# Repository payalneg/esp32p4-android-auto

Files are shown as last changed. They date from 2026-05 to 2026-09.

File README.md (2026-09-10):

🇬🇧 **English** | 🇷🇺 [Русский](README.ru.md)

# VESC Dashboard for ESP32-P4 🛴⚡





[]()

Open-source **800×480 touch dashboard for VESC-powered e-vehicles** —
electric skateboards, e-bikes, scooters, DIY EVs. Live battery percent,
speed, motor / controller temps, voltage, current, odometer — straight off
the VESC CAN bus. Acts as a BLE bridge to VESC Tool so you can tune the
controller while the dashboard is running.

**Bonus**: the same device also speaks the native Android Auto Wireless
protocol — pair your phone over Bluetooth and Google Maps / Spotify /
Cycleway projects onto the same screen. No phone app required.

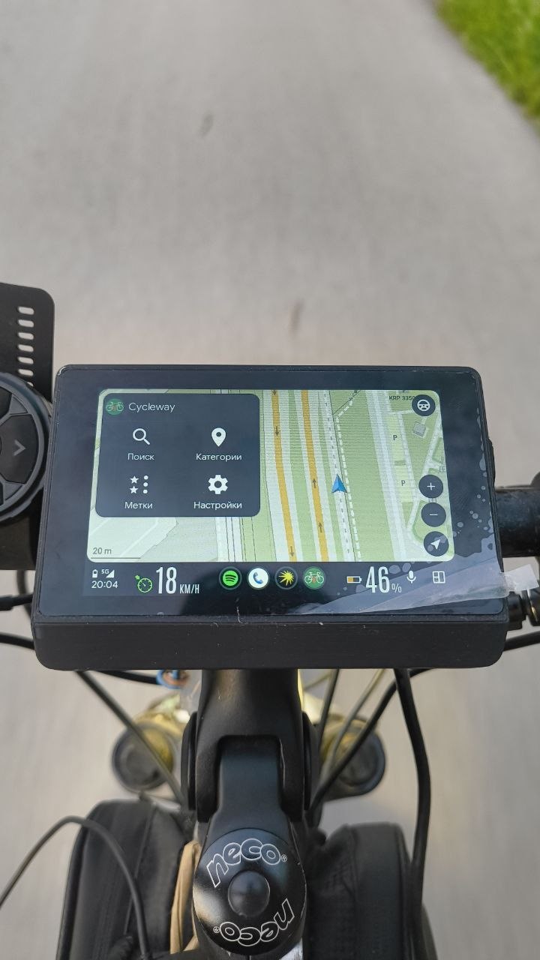
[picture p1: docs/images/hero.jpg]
VESC dashboard — battery, speed, voltage, odometer, motor / controller temps


> 🎬 Short ride demo: [`docs/demo.mp4`](docs/demo.mp4) · [`docs/demo-2.mp4`](docs/demo-2.mp4) · [`docs/demo-3.mp4`](docs/demo-3.mp4)

---

## ✨ Features

### 🛴 Primary — VESC dashboard
- **Live CAN telemetry**: battery %, speed, voltage, current draw, motor
  and FET temperatures, odometer, trip, range estimate, cruise indicator.
- **Trip tracking** — on-screen trip statistics window (distance, Wh,
  efficiency, charts) + a **Reset trip** button, backed by a raw circular
  trip log on a dedicated `triplog` flash partition that survives reboots.
- **On-device VESC Tool config menu** — read / write the controller's motor
  and app config straight from the dashboard screen, run FOC detection, keep
  config / trip backups — no laptop required. Parameter tables are
  code-generated from the VESC Tool XML.
- **BLE NUS bridge** — VESC Tool over Bluetooth Low Energy talks straight
  to the controller through this dashboard, no extra adapter needed.
- **Settings UI** on the device: CAN bitrate, controller ID, persisted
  units / preferences, in-PSRAM ring buffer log viewer.
- **HTTP OTA** with on-screen progress (`scripts/ota_push.sh`).

### 📺 Bonus — Wireless Android Auto
- Native **Android Auto Wireless** projection on the same 800×480 panel —
  no `Wireless Helper` APK, no developer-mode tricks. Pair phone over
  Classic BT once, AA launches itself on every power-on.
- H.264 video decode via `esp_h264` (SW decoder) + PPA-accelerated
  YUV420 → RGB565 shuffle. Native 800×480 @ ~10–15 fps on the panel.
- Touch input forwarded to the phone (GT911 capacitive controller).
- UI beeps / click feedback (System audio channel — required by Gearhead).
- Auto-reconnect to the last paired phone.

Android Auto Cycleway navigation projected on the same screen

### 📱 Companion app (optional)
`aa_bridge` — a small Flutter app ([`flutter-application/`](flutter-application/))
that talks to the head unit over BLE, independently of Android Auto:
- **Notification & media bridge** — phone notifications and now-playing
  metadata / album art mirrored onto the dashboard.
- **Wall clock** — pushes local time over BLE so the dashboard shows `HH:MM`
  with no on-device RTC / coin cell.
- **Firmware update over WiFi or BLE** — the P4 image is bundled in the APK and
  flashed to the head unit over its SoftAP (creds read over BLE automatically,
  or entered / scanned manually) or straight over the BLE link.
- **Device file manager** — browse the head unit's storage (`/vescfs` internal
  LittleFS + microSD) from the phone over BLE: list, download, upload, rename,
  delete. This is how you drop a boot-splash GIF onto the device.

### 🗂️ On-device file browser + boot splash
- **File browser** on the head unit itself (*Settings → Files*) — touch-driven,
  browses `/vescfs` (internal) and `/sdcard` (microSD): folders, sizes, image
  preview, rename / move / delete.
- **Boot splash** — drop an animated `splash.gif` into `/vescfs` and it plays
  full-screen during boot, then hands off to the dashboard. Absent → normal boot.

### 📦 Under the hood
- **Embedded co-firmwares**: ESP32-C6 (`esp-hosted` WiFi slave) and the
  D1 Mini Bluetooth agent are bundled inside the main binary and auto-flashed
  over SDIO / UART on version mismatch.
- **Dual-OTA** layout in 32 MB flash (both slots below the 16 MB boundary),
  plus a dedicated ~12 MB `triplog` partition above it for the raw trip log.

---

## 🔧 Hardware

| Part | Used for | Notes |
|---|---|---|
| **Waveshare ESP32-P4-WIFI6-Touch-LCD-4.3** | always | [Shop](https://www.waveshare.com/esp32-p4-wifi6-touch-lcd-4.3.htm). Main brain — ESP32-P4 + on-board ESP32-C6 WiFi, 800×480 ST7701 MIPI-DSI, GT911 touch. |
| **VESC controller with CAN out** | VESC dashboard | Any rev with CAN. This is the whole point. |
| **TJA1051 CAN transceiver** (prefer `T/3`) | VESC dashboard | 5V → 3.3V CAN level translation |
| **DC-DC step-down 12V → 5V** (≥1 A) | VESC dashboard | Power from VESC / vehicle battery |
| **ESP32-WROOM-32 module** (or any dev board with one) | Android Auto bonus | A bare WROOM-32 module soldered to the P4 board works fine — flip `BT_AGENT_OTA_ENABLED=y` in `idf.py menuconfig` and the P4 flashes it itself over the UART + RST/BOOT lines, no USB-to-serial needed. A D1 Mini ESP32 (or any USB-C ESP32 dev board with Classic BT) works too if you'd rather flash it directly. ESP32-P4 / C6 don't have BT Classic. ~$2–3. |
| Jumper wires, USB-C cables | always | |

If you don't care about Android Auto, you can drop the WROOM entirely —
the dashboard works standalone. With nothing connected on UART and
`BT_AGENT_OTA_ENABLED` left at its default `n`, the P4 silently no-ops
the BT path on every boot.

---

## 🔌 Wiring

<!-- TODO: close-up photo of the J3 header with VESC + D1 Mini wired in -->

**Pinout depends on the board.** The diagrams below are drawn for the
**Waveshare 4.3"** (the default board). For the **Guition JC4880P443C** take the
numbers from the JC4880 column; power, signal directions and the CAN RX divider
are the same on both boards.

| Signal | Waveshare 4.3" | JC4880P443C |
|---|---|---|
| CAN TX → transceiver TXD | GPIO 48 | GPIO 51 |
| CAN RX ← transceiver RXD | GPIO 47 | GPIO 52 |
| BT agent: P4 TX → WROOM RX | GPIO 22 | GPIO 33 |
| BT agent: P4 RX ← WROOM TX | GPIO 21 | GPIO 31 |
| BT agent RST → WROOM EN | GPIO 24 | GPIO 30 |
| BT agent IO0 → WROOM GPIO 0 | GPIO 25 | GPIO 29 |

### 1. Power chain

```text
 12 V battery        ┌────────────┐       ┌──────────────────┐        ┌────────────┐
 (VESC bus)  ───────▶│   DC-DC    │──────▶│  ESP32-P4 board  │───────▶│ WROOM 3V3  │
              +12 V  │ 12 V → 5 V │ +5 V  │  USB-C / 5V pin  │  3V3   │ (optional) │
                     │   ≥ 1 A    │       │  (on-board LDO)  │  (J3)  └────────────┘
                     └────────────┘       └──────────────────┘
```

> ⚠️ If you wire up a D1 Mini for the AA bonus, **power it from the P4's
> 3V3 rail, not from 5V**. The D1 Mini's on-board AMS1117 will burn the
> extra volt as heat for no reason — the P4 board already gives you clean
> 3.3 V on the J3 header.

### 2. VESC CAN bus (primary)

```text
  ESP32-P4                        TJA1051 (prefer T/3)        CAN bus
 ┌─────────────────┐            ┌───────────────┐
 │                 │            │               │
 │ GPIO 48 (TX) ───┼───────────▶│ TXD           │           ┌─────────────┐
 │                 │            │               │           │             │
 │ GPIO 47 (RX) ◀──┼─┬─[1.8kΩ]──┤ RXD      CANH ├─────┬─────┤ CANH        │
 │                 │ │          │               │  [120 Ω]  │    VESC     │
 │                 │[3.3kΩ]     │          CANL ├─────┴─────┤ CANL        │
 │                 │ │          │               │           │             │
 │            GND ─┼─┴──────────┤ GND           │           └─────────────┘
 │                 │            │               │
 │             5V ─┼───────────▶│ VCC           │
 └─────────────────┘            └───────────────┘
```

Pin direction is from the MCU's perspective (NXP convention): on the
TJA1051, **TXD is an input** (MCU drives it), **RXD is an output**
(transceiver drives the MCU).

- **Divider values on RXD**: 1.8 kΩ (series) + 3.3 kΩ (to GND) — or 10 kΩ + 18 kΩ.
  The TJA1051 runs off 5 V, so its RXD swings to 5 V — the divider brings it
  down to a P4-safe 3.3 V. TXD needs nothing: 3.3 V from the P4 drives it fine.
- **120 Ω terminator** across CANH ↔ CANL is **required** — a CAN bus without
  termination works flaky or not at all. Most TJA1051 breakout modules already
  have it soldered on board (look for a resistor marked `121` between the CANH
  and CANL terminals, or measure CANH↔CANL with the module unpowered: ~120 Ω =
  present, open = missing). If your module doesn't have it, **solder a 120 Ω
  resistor across CANH ↔ CANL** as shown in the diagram.
- **TJA1051 vs TJA1051T/3**: if you can choose, get the **T/3** variant — it
  has a dedicated `VIO` pin you can tie to 3.3 V and you can skip the divider
  entirely on RXD.
- Default CAN bitrate is **500 kbps**, controller ID **2** — both configurable
  in `idf.py menuconfig` under *VESC CAN* (`VESC_CAN_SPEED_KBPS`,
  `VESC_CAN_CONTROLLER_ID`).

#### Dual-motor (two-head) boards

Dual ESCs (Flipsky Dual, Spintend UBOX, MakerX dual, …) are **two VESC nodes on
one CAN bus**, each with its own controller ID. To use both heads:

1. In **Settings → Second head**, turn the toggle on and set **Second head ID**
   to the second controller's CAN ID (the primary is the usual *Target VESC ID*).
2. On **both** heads, in VESC Tool enable **App → General → Send status over CAN**
   with status messages **1–5** at **50 Hz** (the default rate when enabled), and
   give the two heads **distinct CAN IDs** (e.g. 0 and 1).

The 50 Hz status rate is required, not optional: the master VESC only folds a
peer into its combined totals while that peer's CAN status is **< 100 ms old**,
and the dashboard reads the second head's temperatures from those same status
frames. At a low status rate the combined Ah/Wh/power readout flickers.

What you get on a dual board:

- **Temperatures** show both heads as `h1/h2` (e.g. `34/37`); falls back to a
  single value if the second head's status isn't seen.
- **Battery / Ah / Wh / power** are the **combined** totals of both motors — the
  master VESC sums them itself (we just read its *setup* values), so no extra
  CAN polling is added.
- **Speed, distance and voltage** are taken from the primary head.
- **ESC NOT CONNECTED** shows if *either* head goes silent.
- The **VESC config menu** gains a **Head 1 / Head 2** selector so you can read
  and write each head's MCCONF/APPCONF independently.

### 3. D1 Mini ESP32 ↔ P4 (only for the AA bonus)

The P4 board exposes a `J3` header on the bottom edge with the free expansion
pins. The USB-C debug console (GPIO 37/38) stays usable while this is wired up.

```text
  ESP32-P4 (J3 header)             ESP32-WROOM-32 / D1 Mini
 ┌─────────────────────┐          ┌─────────────────────────┐
 │ GPIO 22 (UART1 TX) ─┼─────────▶│ GPIO 3 (RX0)            │
 │ GPIO 21 (UART1 RX) ◀┼──────────┤ GPIO 1 (TX0)            │
 │ GPIO 24 ────────────┼─────────▶│ EN     — chip reset     │
 │ GPIO 25 ────────────┼─────────▶│ GPIO 0 — boot select    │
 │ 3V3 (out) ──────────┼─────────▶│ 3V3    — power in       │
 │ GND ────────────────┼──────────┤ GND                     │
 └─────────────────────┘          └─────────────────────────┘
```

`EN` / `GPIO 0` are the standard ESP32 reset + boot-mode pins — same combo
the `esp_serial_flasher` uses on any ESP32 chip; on D1 Mini dev boards
they're already broken out to the `EN` and `D3` (= GPIO 0) headers
respectively.

The RST/BOOT lines let the main P4 firmware automatically re-flash the BT
agent over UART when their versions diverge — you only ever flash the D1 Mini
manually once.

---

## 🚀 Build & Flash

### Prerequisites

- **ESP-IDF v5.5 or newer** (tested with v5.5.3).
- Install both targets — `esp32p4` is mandatory, `esp32` only if you want
  the Android Auto bonus.

```bash
git clone --recursive https://github.com/espressif/esp-idf.git
cd esp-idf && ./install.sh esp32,esp32p4
. ./export.sh
```

### 1. Main firmware — ESP32-P4 (dashboard + AA)

```bash
cd esp32p4-android-auto
idf.py set-target esp32p4
idf.py -p /dev/cu.usbmodem* flash monitor
```

A plain `idf.py` build targets the **Waveshare 4.3"** board (the default).

> The ESP32-C6 WiFi co-firmware (`network_adapter.bin`) is bundled into the
> main binary via `EMBED_FILES` and pushed to the C6 over SDIO on boot when
> versions don't match — you don't flash the C6 separately.

#### Multiple boards

The firmware supports more than one board — and not all of them are ESP32-P4.
Pick the board with `scripts/build_board.sh <board> <idf.py args…>`, which uses
a per-board build directory and layers the matching
`sdkconfig.defaults.<board>` overlay:

| Board | Slug | Chip | Panel | Flash | Notes |
|---|---|---|---|---|---|
| Waveshare ESP32-P4-WIFI6-Touch-LCD-4.3 | `waveshare` | ESP32-P4 | 800×480 | 32 MB | default (also what plain `idf.py` builds) |
| Guition JC4880P443C_I_W | `jc4880` | ESP32-P4 | 800×480 | 16 MB | ST7701S, smaller partition table (`partitions_16mb.csv`) |
| Waveshare ESP32-S3-Touch-LCD-4 | `s3touch4` | ESP32-S3 | 480×480 | 16 MB | **VESC dashboard only, no Android Auto** — see [docs/board_s3touch4.md](docs/board_s3touch4.md) |

```bash
scripts/build_board.sh                              # build firmware for ALL boards
scripts/build_board.sh waveshare flash monitor
scripts/build_board.sh jc4880 -p /dev/cu.usbmodem* flash monitor
scripts/build_board.sh s3touch4 -p /dev/cu.usbmodem* flash monitor
```

Run with no board (or `all`) to build every board's image in one go.

What differs between the two P4 boards (everything else — WiFi/SDIO→C6, touch
I2C, SD, most of the I2S bus — is shared): MIPI-DSI panel timing + vendor init,
LCD backlight/reset pins, the BT-agent UART pins, the CAN RX/TX pins, flash
size and the partition table. The board is chosen by the Kconfig `BOARD_MODEL`
choice (`CONFIG_BOARD_WAVESHARE_43` / `CONFIG_BOARD_JC4880P443C` /
`CONFIG_BOARD_S3_TOUCH_LCD_4`); see the `#if CONFIG_BOARD_JC4880P443C`
branches in the BSP and `main/bt_link.h`.

The ESP32-S3 board is a bigger step sideways: its Wi-Fi and BLE are on the
chip itself (no ESP32-C6), its panel is a square 480×480 RGB one, and it has
no PPA blitter, no hardware JPEG and no external BT agent — so the whole
Android Auto side is compiled out (`CONFIG_AA_ENABLE`, ESP32-P4 only) and what
remains is the dashboard with CAN, BLE, pedal assist, trip history, the web UI
and OTA. It has its own 480×480 GUI Guider project (`Super_VESC_Display_480/`)
and its own BSP; `scripts/build_board.sh` switches `IDF_TARGET` for it.

The pins you actually wire (CAN transceiver and BT agent) are in the table under
**🔌 Wiring** above. JC4880's internal panel pins (LCD backlight `23`, reset `5`)
are set in the BSP — you don't solder those.
The 16 MB layout fits two 5 MB OTA slots + 1 MB storage + ~4.9 MB trip log —
the app image (~3.8 MB) has ~1.2 MB (24%) of headroom in each slot, so watch
the size as the firmware grows.

### 2. (Optional) BT agent firmware — D1 Mini ESP32

Only needed if you want the Android Auto bonus. Two ways to do it:

**A. Let the P4 flash it (best for a bare soldered WROOM).** Enable
`BT_AGENT_OTA_ENABLED=y` in `idf.py menuconfig` (under
*Project → BT Agent OTA*) and rebuild. On every boot the P4 checks the
agent's `BT-VER:` line over UART and reflashes it from the firmware blob
embedded in `components/bt_agent_fw/` if the version doesn't match. So a
bare soldered WROOM-32 comes up fully provisioned the first time you power
on. (Default is `n` — without it the BT path is a no-op even if a WROOM
is wired up.)

**B. Flash it yourself.** Plug a dev board with USB into your laptop:

```bash
cd tools/bt_agent
idf.py set-target esp32
idf.py -p /dev/cu.usbserial-* flash monitor
```

See [`tools/bt_agent/README.md`](tools/bt_agent/README.md) for the full agent
boot log walkthrough and what the SSP pairing dialogue looks like.

### 3. VESC LISP script — for cruise control + speed profiles

[`lisp/main.lisp`](lisp/main.lisp) runs on the **VESC controller** (not on
the P4). It adds cruise control via the PPM `RX` pin and three speed-profile
presets via `TX`, plus exposes the cruise state to the dashboard's LISP
poll channel — that's what drives the cruise indicator on screen.

Open *VESC Tool → VESC Packages → Lisp Scripting*, load `lisp/main.lisp`,
**Upload** → **Activate** → save to flash. See [`lisp/README.md`](lisp/README.md)
for details and how to customise the speed presets.

Without this script the dashboard still shows live telemetry — only the
cruise indicator and profile-switch beeps are lost.

### 4. OTA updates after the first flash

Once the head unit is on its SoftAP (default IP `192.168.4.1`), push new
firmware over HTTP from any laptop joined to the same AP:

```bash
scripts/ota_push.sh 192.168.4.1
```

You'll see a progress bar on the device screen, then it reboots into the new
slot.

---

## 📱 Using it

### Dashboard mode (default)

Power up. The dashboard comes up immediately on the screen showing whatever
the VESC is reporting over CAN — battery, speed, temps, etc. Tap into Settings
to change units, CAN bitrate, controller ID, or open the log viewer.

While the dashboard is running, **VESC Tool can connect over Bluetooth LE**
(NUS bridge) just like to any other VESC adapter.

### Switching between modes

**Three-finger tap** (any three fingers on the screen for ~100 ms) toggles
between the **VESC dashboard** and the **Android Auto projection**. The
gesture works in either direction, in both modes, and only fires once per
gesture — your fingers have to lift before it can fire again, so it won't
leak through to the phone as a stray touch.

### Android Auto bonus (after flashing the BT agent)

1. The screen also shows **"Waiting for phone"** in a corner with the SoftAP
   SSID / IP.
2. On the phone: *Settings → Bluetooth → Pair new device → **ESP32-P4 AA***.
3. Accept the SSP pairing prompt.
4. The phone joins the head unit's WiFi automatically and launches Android
   Auto. The screen flips to AA projection; the VESC dashboard runs on as
   an overlay (battery %, speed) on top of the AA video.

After the first pairing the head unit remembers the phone, and every
subsequent power-on auto-reconnects without prompts.

### Companion app (notifications, media, clock, WiFi flashing)

Optional Android app in [`flutter-application/`](flutter-application/). Build
and install:

```bash
cd flutter-application
flutter build apk --release
adb install -r build/app/outputs/flutter-apk/app-release.apk
```

- **Pair**: open the app → it scans for the head unit over BLE → tap to
  connect. Auto-reconnects after that.
- **Notifications / media**: grant the notification-access permission when
  prompted; phone notifications + now-playing info appear on the dashboard.
  The dashboard clock starts showing `HH:MM` once the app is connected.
- **Update firmware over WiFi**: *Home → Update head unit firmware*. The app
  reads the SoftAP credentials over BLE (or you scan / type them), joins that
  WiFi and uploads the firmware bundled in the APK. The head unit verifies and
  reboots onto the new version — keep it powered throughout. The bundled image
  is staged from `build/` by [`scripts/stage_firmware_asset.sh`](scripts/stage_firmware_asset.sh).

### Device files & boot splash GIF

Two ways to manage files on the head unit:

- **On device**: *Settings → Files* — a touch file browser over `/vescfs`
  (internal storage) and `/sdcard` (microSD if inserted). Browse, preview
  images, rename / move / delete.
- **From the phone**: *Home → Device files* (shown when connected to firmware
  that supports it) — list folders, download to the phone, upload from the
  phone, rename, delete, mkdir.
- **From a browser**: `http://android-auto.local/files` (or the SoftAP gateway
  IP) — the same browse / preview / upload / rename / move / delete over both
  drives.

### Web LISP editor

`http://android-auto.local/lisp` — a full LispBM editor for the script running
on the VESC, from any browser on the same network (the phone joins the head
unit's SoftAP anyway):

- syntax highlighting, line numbers, rainbow + matching parens, find/replace,
  block indent, auto-close;
- a linter for the mistakes that cost the most time here: paren balance,
  unterminated strings, `@const-start` / `@const-end` pairing, defuns left
  outside the const block, and threads started before the function they run
  is defined;
- the on-device script library (`/vescfs/lisp` and microSD) with open, save,
  rename / move, delete, mkdir and upload;
- **Read VESC** / **Upload** / **Upload + Run** / **Start** / **Stop** over CAN
  with a progress bar (the transfer runs asynchronously, so the rest of the
  server stays responsive);
- a live console of the script's `(print ...)` output, plus a REPL line for
  evaluating an expression without reflashing the script;
- LISP stats (CPU / heap / memory / stack and exported variables), polled only
  while that tab is open.

Turn it off with `CONFIG_LISP_HTTP_ENABLED=n` (costs ~15 KiB of flash).
`scripts/lisp_web_mock.py` serves the same page against a fake device, for
working on the editor without a board.

**Set a startup GIF**: upload an animated GIF to `/vescfs` via *Device files*
and name it **`splash.gif`** (upload it already named that, or rename it after
upload). On the next boot it plays full-screen, then the dashboard takes over.
Keep it small — `/vescfs` is ~4 MB on the Waveshare board, ~1 MB on jc4880.

---

## 🗺️ Roadmap / Status

| Area | Status | Notes |
|---|---|---|
| VESC RT data over CAN | ✅ | Battery %, speed, voltage, current, temps, odometer |
| Trip statistics window + persistent trip log | ✅ | Per-trip metrics / charts + Reset trip; raw circular log on the `triplog` partition |
| On-device VESC Tool config menu + FOC detection | ✅ | Read / write controller config from the screen; param tables generated from the VESC Tool XML |
| VESC LISP poll | ✅ | Cruise indicator + custom stats (requires [`lisp/main.lisp`](lisp/main.lisp) on the controller) |
| BLE NUS bridge (VESC Tool over BLE) | ✅ | Works concurrently with AA |
| Companion app — notifications / media / clock bridge | ✅ | Flutter `aa_bridge` over BLE |
| Companion app — firmware update over WiFi / BLE | ✅ | Bundled image POSTed to the SoftAP OTA endpoint, or streamed over the BLE link |
| On-device file browser (`/vescfs` + microSD) | ✅ | Touch UI in *Settings → Files*; image preview, rename / move / delete |
| Companion app — file manager over BLE | ✅ | Browse / download / upload / rename / delete the head unit's storage from the phone |
| Boot splash GIF | ✅ | Animated `/vescfs/splash.gif` shown during boot (upload via the app's file manager) |
| Settings UI + PSRAM log viewer | ✅ | Logs survive resets, viewable on device |
| HTTP OTA + on-screen progress | ✅ | `scripts/ota_push.sh` |
| (Bonus) AA Wireless video (H.264) | ✅ | Native 800×480 @ ~10–15 fps; SW decode + RGB shuffle is the bottleneck |
| (Bonus) Touch input forwarding | ✅ | GT911 → AA `TouchEvent` protobuf |
| (Bonus) System audio channel | ✅ | UI beeps; required by Gearhead to project at all |
| (Bonus) Auto-reconnect to last phone | ✅ | Bonded list in NVS on the BT agent |
| Media / Speech audio channels | 🟡 | Dropped on purpose — no audio sink |
| Pure BT Classic on P4 (no D1 Mini) | ❌ | Not possible — ESP32-P4 has no BT Classic radio |

---

## 🖨️ 3D-printable enclosure

STL / STEP files for the case live in [`3d-model/`](3d-model/). Print
settings, recommended materials and assembly notes will be added there as the
design firms up.

<!-- TODO: render or photo of the printed enclosure -->

---

## 📁 Repository layout

```
.
├── main/                       # ESP32-P4 firmware — VESC, UI, AA stack, OTA, BLE
├── components/
│   ├── esp32_p4_wifi6_touch_lcd_4_3/  # Waveshare BSP (LVGL, ST7701 DSI, GT911 touch)
│   ├── vesc_can/               # CAN driver for VESC (RT data + LISP poll)
│   ├── vesc_ui/                # Dashboard UI — thin wrapper; real UI source is globbed from Super_VESC_Display/{generated,custom}/
│   ├── vesc_config/            # On-device VESC Tool config menu (param tables from XML, FOC detection)
│   ├── trip_log/               # Raw circular trip log on the dedicated triplog partition
│   ├── dev_settings/           # Settings screen + persisted prefs
│   ├── log_capture/            # PSRAM ring-buffer logger
│   ├── bt_agent_fw/            # Embeddable bt_agent firmware blob (AA bonus)
│   ├── c6_ota_partition/       # Embedded ESP32-C6 firmware (network_adapter.bin)
│   └── qr_info/                # QR code with WiFi creds for the phone
├── Super_VESC_Display/         # NXP GUI Guider project — the dashboard UI source (generated/ + custom/), compiled into the firmware via vesc_ui
├── tools/
│   ├── bt_agent/               # D1 Mini ESP32 firmware (Classic BT + SPP)
│   ├── c6_slave_fw/            # Sources of the bundled C6 firmware (gitignored, see CLAUDE.md)
│   └── c6_ota_flasher/         # Standalone fallback C6 flasher
├── scripts/                    # capture.sh (Wireshark), ota_push.sh, extract_yuv.py, release.sh
├── lisp/                       # VESC LISP script (cruise + speed profiles) — runs on the VESC, not the P4
├── 3d-model/                   # STL / STEP files for the printed enclosure
├── release/                    # Versioned release artifacts (P4 .bin + companion .apk)
├── docs/images/                # Photos / screenshots used by this README
├── research/                   # Reference upstream sources (gitignored)
├── partitions.csv              # Dual-OTA layout (both slots below 16 MB) + triplog partition
├── CLAUDE.md                   # Original architecture notes / design history
└── README.md
```

---

## 🙏 Credits & references

- The **[VESC project](https://vesc-project.com/)** by *Benjamin Vedder* —
  the open-source motor controller this dashboard is built around.
- [**aasdk**](https://github.com/f1xpl/aasdk) and [**openauto**](https://github.com/f1xpl/openauto) by *f1xpl* — the AA Wireless protocol reference for the bonus mode.
- [**headunit-revived**](https://github.com/andreknieriem/headunit-revived) by *andreknieriem* — wireless-mode reference.
- [**esp-h264**](https://github.com/espressif/esp-h264) and [**esp-hosted**](https://github.com/espressif/esp-hosted) by *Espressif*.
- [**Waveshare ESP32-P4-WIFI6-Touch-LCD-4.3 wiki**](https://github.com/waveshareteam/ESP32-P4-WIFI6-Touch-LCD-4.3) — board BSP and example code.

---

## 📜 License

Released under the **GNU General Public License v3.0** — see [`LICENSE`](LICENSE).

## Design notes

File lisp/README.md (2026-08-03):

# VESC LISP script

`main.lisp` runs on the **VESC controller's** built-in LISP runtime (not on
the ESP32-P4). It does three things that the dashboard relies on:

1. **Cruise control** via the PPM `RX` pin button:
   - press once → lock current speed (switch into speed-control mode)
   - press throttle or brake → release cruise
   - the dashboard reads `cruise-active` over the LISP poll channel and
     lights the cruise indicator
2. **Speed profiles** — three presets (25 / 40 / 60 km/h, configurable in
   `apply-profile`), switchable two ways:
   - the PPM `TX` pin button cycles through them (`switch-profile`)
   - the on-screen panel picks one directly (`panel-set-profile`)
   Different beep tones confirm each profile change.
3. **Quick-action panel** — the swipe-out drawer on the P4 dashboard
   (left-edge swipe). This script is the *server* for it: the P4 asks
   "describe your controls" and we answer with a list the firmware renders
   (toggles / buttons / numbers / read-only values); interactions come back
   here. The starter set: **Throttle on/off**, a **Beep** button, a **Beep Vol**
   number (persisted) and the three **profile buttons** — a radio group, exactly
   one lit. A **Traction Control** toggle + sensitivity is included but commented
   out (single motor → native VESC TC is a no-op).

Without this script the dashboard still shows live telemetry (battery,
speed, voltage, temps over standard VESC CAN), but the cruise indicator,
profile switching and the quick-action panel won't work.

## Quick-action panel — describing the menu in LISP

The drawer is **data-driven**: this script tells the P4 *what controls to draw*,
the P4 renders them and sends back interactions. Nothing about the menu is
hard-coded in the firmware, so you change the menu by editing LISP only — no
firmware rebuild.

> **New here? Read "Add a control — the simple version" just below.** The
> byte-level sections after it are reference — you rarely need them.

### Add a control — the simple version

A control = one row in the drawer. You describe it in LISP, the P4 draws it.
Four kinds: **toggle** (on/off), **button** (press once), **number**
(−/value/+), **label** (read-only readout).

To add one, edit **3 spots** near the bottom of this file, all keyed by a
unique **id** number:

1. `panel-send-ui`    — bump the count, add one "describe" line.
2. `panel-send-state` — add its live value (skip for buttons).
3. `panel-action`     — say what happens when tapped (skip for labels).

Copy-paste templates — replace `ID`, `"Label"`, `myvar`, and the action:

```lisp
; TOGGLE  (on/off; myvar is 0 or 1)
;  ui:     (pu8 ID) (pu8 1) (pstr "Label") (pu8 myvar)
;  state:  (pu8 ID) (pi32 (* myvar 1000))
;  action: ((= cid ID) (setq myvar (if (> val 0.5) 1 0)))

; BUTTON  (momentary)
;  ui:     (pu8 ID) (pu8 2) (pstr "Label")
;  state:  — none —
;  action: ((= cid ID) (do-something))

; NUMBER  (−/value/+; this one is 0..100 step 5)
;  ui:     (pu8 ID) (pu8 3) (pstr "Label")
;          (pi32 0) (pi32 100000) (pi32 5000) (pi32 (* myvar 1000)) (pstr "")
;          ;        ^min×1000     ^max×1000   ^step×1000 ^value×1000 ^unit
;  state:  (pu8 ID) (pi32 (* myvar 1000))
;  action: ((= cid ID) (setq myvar (to-i32 val)))

; LABEL   (read-only; e.g. a live temperature)
;  ui:     (pu8 ID) (pu8 4) (pstr "Label") (pi32 (* (get-temp-mot) 1000)) (pstr "C")
;  state:  (pu8 ID) (pi32 (* (get-temp-mot) 1000))
;  action: — none —
```

Rules of thumb:
- **count** is the byte right after `0x81` (in `panel-send-ui`) / `0x82` (in
  `panel-send-state`). It must equal how many controls you actually list — add
  one, bump both.
- **id** is just a label; keep each unique, order doesn't matter.
- Numbers travel ×1000 (so `50` → `(pi32 (* 50 1000))`) — that's how decimals
  survive as whole numbers; the P4 divides back. Strings: `(pstr "...")`, empty
  unit = `(pstr "")`.

### Добавить контрол — по-простому

Контрол = одна строка в выезжающей панели. Ты описываешь её в LISP, а P4 рисует.
Четыре вида: **toggle** (вкл/выкл), **button** (нажал один раз), **number**
(−/значение/+), **label** (просто показать, без нажатия).

Чтобы добавить, правишь **3 места** внизу файла, всё завязано на уникальный
номер **id**:

1. `panel-send-ui`    — увеличь счётчик и добавь одну строку-«описание».
2. `panel-send-state` — добавь живое значение (для кнопки — не нужно).
3. `panel-action`     — что делать при нажатии (для label — не нужно).

Шаблоны — подставь `ID`, `"Название"`, `myvar` и действие:

```lisp
; TOGGLE  (вкл/выкл; myvar = 0 или 1)
;  ui:     (pu8 ID) (pu8 1) (pstr "Название") (pu8 myvar)
;  state:  (pu8 ID) (pi32 (* myvar 1000))
;  action: ((= cid ID) (setq myvar (if (> val 0.5) 1 0)))

; BUTTON  (разовое нажатие)
;  ui:     (pu8 ID) (pu8 2) (pstr "Название")
;  state:  — нет —
;  action: ((= cid ID) (что-то-сделать))

; NUMBER  (−/значение/+; тут 0..100 шаг 5)
;  ui:     (pu8 ID) (pu8 3) (pstr "Название")
;          (pi32 0) (pi32 100000) (pi32 5000) (pi32 (* myvar 1000)) (pstr "")
;          ;        ^мин×1000     ^макс×1000  ^шаг×1000  ^знач×1000  ^единица
;  state:  (pu8 ID) (pi32 (* myvar 1000))
;  action: ((= cid ID) (setq myvar (to-i32 val)))

; LABEL   (только показать; напр. температуру)
;  ui:     (pu8 ID) (pu8 4) (pstr "Название") (pi32 (* (get-temp-mot) 1000)) (pstr "C")
;  state:  (pu8 ID) (pi32 (* (get-temp-mot) 1000))
;  action: — нет —
```

Памятка:
- **count** — это байт сразу после `0x81` (в `panel-send-ui`) / `0x82` (в
  `panel-send-state`). Он должен равняться числу реально перечисленных контролов:
  добавил один — увеличь оба.
- **id** — просто метка; держи уникальным, порядок не важен.
- Числа едут ×1000 (`50` → `(pi32 (* 50 1000))`) — так дроби переживают пересылку
  целыми, P4 делит обратно. Строки: `(pstr "...")`, пустая единица = `(pstr "")`.

### How the conversation works

```
        user swipes from the left edge of the dashboard
                          │
  P4 ─ REQ_UI ──────────► us        "describe your controls"
  us ─ UI_DESC ─────────► P4        list of controls (this is the menu)
            … drawer rendered, then every ~200 ms while open:
  P4 ─ REQ_STATE ───────► us
  us ─ STATE ───────────► P4        live values (refresh toggles/numbers/labels)
        user taps a control
  P4 ─ ACTION ──────────► us        (control-id, new value)
  us ─ STATE ───────────► P4        echo the applied state back
```

> **Three copies of these rules exist and must stay in step.** This file is the
> human one. The in-app AI assistant is told the same protocol in
> `flutter-application/lib/agent/lisp_reference.dart` (byte layout) and
> `agent_prompt.dart` (the fail-silently rules), and
> `flutter-application/lib/agent/lisp_lint.dart` enforces it before letting the
> assistant flash. Change the wire format and you change all three, plus
> `components/vesc_can/`.

Transport is `COMM_CUSTOM_APP_DATA` (id 36): the firmware delivers inbound
frames to the `event-data-rx` event, and we answer with
`(send-data buf 2 reply-can-id)` — interface `2` is CAN, `reply-can-id` is the
P4's own controller id, which it puts in every request (needs VESC FW **6.05+**
for the explicit-interface form of `send-data`). The C side is
`components/vesc_can/vesc_lisp_panel.{c,h}`; everything below is its mirror.

### Conventions

- **Framing.** Every payload starts with the magic bytes `0x56 0x50` ('V' 'P'),
  then a 1-byte message type, then the body. The `COMM_CUSTOM_APP_DATA` byte
  itself is added/stripped by the firmware, so it never appears in `data` you
  receive or in the buffer you send.
- **Numbers are scaled integers.** Every float on the wire is
  `int32 = round(value * 1000)`, **big-endian**. So `0` → `0`, `100` → `100000`,
  `5` → `5000`, `tc-sens` → `(* tc-sens 1000.0)`. The P4 divides by 1000 again.
- **Strings are NUL-terminated.** A LISP string literal *is* a byte array that
  already ends in `0`, and `buflen` counts that terminator — so `(pstr "Beep")`
  emits `B e e p \0` and `(pstr "")` emits a single `\0` (used for "no suffix").

### Append helpers (already in `main.lisp`)

These write into the scratch buffer `pbuf` at the running index `pi`:

| helper | writes |
|---|---|
| `(pu8 v)` | one byte |
| `(pi32 v)` | `v` as big-endian int32 (you pre-multiply ×1000)|
| `(pstr s)` | the string `s` **including** its NUL terminator |

`pbuf` is `(bufcreate 128)` — zero-filled and over-sized on purpose: the P4 reads
exactly `count` controls and ignores trailing zeros, so you only need to grow
the `128` if a *single* reply gets bigger than that. The current `UI_DESC` is
102 B, so there is room for roughly one more short control before you must bump
it (the whole buffer goes on the wire every reply, so don't over-grow it).

### Message catalogue

**Inbound — what the P4 sends us** (`data`, magic already validated):

| msg | bytes |
|---|---|
| `REQ_UI` `0x01` | `[0]=V [1]=P [2]=0x01 [3]=reply-id` |
| `ACTION` `0x02` | `… [2]=0x02 [3]=reply-id [4]=ctrl-id [5..8]=i32 value*1000`  |
| `REQ_STATE` `0x03` | `… [2]=0x03 [3]=reply-id` |

**Outbound — what we send back** (`send-data pbuf 2 reply-id`):

```
UI_DESC (0x81):  0x56 0x50 0x81  <ver=1> <count>   then <count> controls
STATE   (0x82):  0x56 0x50 0x82  <count>           then <count> (id, value)
```

A control inside `UI_DESC` is `<id:u8> <type:u8> <label:str>` followed by a
type-specific tail:

| control | `type` | tail after `id type label` |
|---|:---:|---|
| toggle  | `1` | `<state:u8 0/1>` |
| button  | `2` | *(nothing)* — momentary |
| number  | `3` | `<min:i32> <max:i32> <step:i32> <value:i32> <suffix:str>` |
| label | `4` | `<value:i32> <suffix:str>` (read-only readout) |

An entry inside `STATE` is just `<id:u8> <value:i32>`. Send a value for every
control that can change (toggles, numbers, labels); buttons have no state, so
just leave them out of `STATE`.

**ACTION value semantics** (what arrives in `panel-action`): toggle → `0.0`/`1.0`,
button → `1.0` (a press), number → the new value in real units (e.g. `55.0`).

> Step-by-step with copy-paste templates is in **"Add a control — the simple
> version"** above. The current `main.lisp` panel is a live worked example:
> Throttle (toggle, id 1), Beep (button, id 4), Beep Vol (number, id 5, persisted)
> and the profile radio group — Slow / Medium / Fast (toggles, ids 10/11/12).
> Traction Control (ids 2/3) is there but commented out — a ready template to
> copy.
>
> **Radio group pattern** (the profiles): N toggles whose `state` is
> `(if (= sel K) 1 0)`, and each action sets `sel` to *its own* index while
> ignoring the incoming value. Tapping the lit row therefore sends `0` and does
> nothing — the `STATE` echo lights it straight back up.

## How to flash

Open **VESC Tool → VESC Packages → Lisp Scripting**, load
`lisp/main.lisp`, then **Upload** and **Activate**. Save to flash so it
survives reboot.

## Customising

- Speed presets — edit `apply-profile` (the three `conf-set 'max-speed`
  lines near the top of the file). Adding/removing one means: `num-profiles`,
  the `beep-freq` table, and the panel rows (ids 10..12 in `panel-send-ui` /
  `panel-send-state` / `panel-action`) — keep the labels in step with the
  speeds, the P4 only draws what this script says.
- Throttle/brake deadzones — `monitor-throttle-brake`.
- Quick-action panel controls — the `panel-*` functions at the bottom (see
  "Add a control — the simple version" above).
- Traction-control template — uncomment the TC controls + `monitor-traction`
  spawn; tune the `limit` formula. (Multi-motor only; no-op on a single motor.)

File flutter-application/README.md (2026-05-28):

# aa_bridge

A new Flutter project.

## Getting Started

This project is a starting point for a Flutter application.

A few resources to get you started if this is your first Flutter project:

- [Lab: Write your first Flutter app](https://docs.flutter.dev/get-started/codelab)
- [Cookbook: Useful Flutter samples](https://docs.flutter.dev/cookbook)

For help getting started with Flutter development, view the
[online documentation](https://docs.flutter.dev/), which offers tutorials,
samples, guidance on mobile development, and a full API reference.

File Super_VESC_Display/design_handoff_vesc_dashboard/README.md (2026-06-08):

# Handoff: VESC E-Bike Dashboard (Cyberpunk Amber)

## Overview
A full-screen instrument cluster for an electric bike running a **VESC** motor controller.
Target hardware display: **800 × 480 px** (landscape, fixed resolution).
The design shows live ride telemetry — speed, battery, power, temperatures — in a
"cyberpunk" amber-on-black aesthetic with a 7-segment LCD numeric typeface and warm glow.

The chosen direction is **Variant A — "Classic Reskin"**: it keeps the exact information
layout of the original VESC stock display (battery left, big speed center, power right,
secondary readouts along the bottom) and reskins it.

## About the Design Files
The files in this bundle are **design references created in HTML/React (via Babel in the
browser)** — a prototype showing the intended look and behavior. They are **not** meant to
be shipped as-is to the device.

The task is to **recreate this design in the target environment** for the VESC display —
e.g. an embedded UI framework (LVGL/C, Qt/QML), a React/web kiosk, or whatever renders on
the actual screen — using that environment's patterns. If no environment exists yet, pick
the most appropriate one for an 800×480 embedded display. Treat the HTML as the visual
spec, not the implementation.

## Fidelity
**High-fidelity (hifi).** Final colors, typography, spacing, layout and glow treatment are
all intended as-shown. Recreate pixel-accurately at 800×480. The numbers shown are sample
telemetry values (see Design Tokens → Sample data) — wire them to real VESC data.

## Canvas / Coordinate system
- Fixed art-board: **800 × 480 px**, origin top-left. All measurements below are in this space.
- The screen is divided into 3 horizontal bands:
  - **Top status bar** — height **50px**
  - **Main row** — height **340px** (battery | speed | power)
  - **Bottom readout row** — height **90px**
  - (50 + 340 + 90 = 480)

## Screens / Views

### Screen: Ride Dashboard (single screen)
**Purpose:** at-a-glance riding telemetry.

**Layout (top → bottom):**

**1. Top status bar** (`height 50px`, padding `0 20px`, bottom border `1px solid rgba(255,122,26,0.14)`)
A single flex row, `justify-content: space-between`, font-size 17px:
- `VESC MODE` (nav label, amber-bright, glow-s)
- trip timer `0:48:12` (7-seg, 18px, opacity .8)
- `STATISTICS` (nav label)
- clock `14:32` (7-seg, 18px, opacity .8)
- `SETTINGS` (nav label)
- Bluetooth group: a 8px blue dot (`#2aa9ff`, glow) + `BT` label in blue
  Nav labels: font Chakra Petch 700, letter-spacing .12em, uppercase, `white-space: nowrap`.

**2. Main row** (`height 340px`, flex row):

  **a) BATTERY column** — fixed width **210px**, padding `16px 18px 10px`, right border `1px solid grid-line`, flex column:
  - `BATTERY` label (Chakra Petch 600, 22px, uppercase, letter-spacing .18em, color `--label`)
  - Value row (margin-top 14px, align-items baseline, gap 8px): big `73` (7-seg, **46px, "hot" style**) + `%` unit (22px)
  - Sub row (margin-top 6px, gap 6px): `6.4` (7-seg, 24px, **no ghost**) + `Ah` unit (16px)
  - **Vertical segmented bar** — fills remaining height (`flex:1`, margin `12px 0 8px`), 16 cells, fill from bottom, `73%` lit
  - Footer row (space-between, baseline): `RANGE` label (16px) + `38` (7-seg 24px, no ghost) + `KM` unit (15px)

  **b) SPEED column** — `flex: 1` (center), flex column centered:
  - `SPEED · KM/H` label (Chakra Petch 600, 17px, letter-spacing .32em, nowrap, **margin-bottom 20px**)
  - `42` — the hero number (7-seg, **166px, "hot" style**, line-height .9). Value is zero-padded to 2 digits.
  - `SPORT` — ride mode label (Chakra Petch 600, 15px, letter-spacing .3em, color `--amber`, margin-top 18px)
  - *(Note: an earlier version had a curved "smile" arc gauge under the speed — it was intentionally removed. Do not add it.)*

  **c) POWER column** — fixed width **210px**, padding `16px 18px 10px`, left border `1px solid grid-line`, flex column, **right-aligned** (`align-items: flex-end`):
  - `POWER` label (22px)
  - Value row (baseline, gap 8px): `2.8` (7-seg, **46px, hot**) + `kW` unit (22px)
  - Sub row (gap 6px): `24.5` (7-seg, 24px, no ghost) + `A` unit (16px)
  - **Vertical segmented bar** — fills remaining height, 16 cells, lit to `power/maxKw` = `2.8/4.5 ≈ 62%`, **warn (red) above 80%**
  - Footer row (space-between, full width, baseline): `MAX` label (16px) + `4.5` (7-seg 24px, no ghost) + `KW` unit (15px)

**3. Bottom readout row** (`height 90px`, top border `1px solid grid-line`, flex row of 5 equal cells):
Each cell: flex column, centered, gap 7px, left border `1px solid grid-line` (except first). Contains a small label (Chakra Petch 600, 14px) above a value (7-seg, 26px, no ghost) + unit (14px). The five cells:
1. `VOLTAGE` — `58.4` `V`
2. `TRIP` — `12.6` `KM`
3. `ODO` — `6436` `KM`
4. `M·TEMP` — `47` `°C`  (motor temp; turns **red/warn** if > 70)
5. `C·TEMP` — `39` `°C`  (controller temp; turns **red/warn** if > 70)

## Components (reusable primitives)

### `Seg` — 7-segment numeric readout
The signature element. A number rendered in the **DSEG7 Classic** font with a warm glow.
Behind the lit value sits an optional dim "ghost" layer showing all segments as `8`s
(simulating unlit LCD segments) at `--amber-dim` with no glow.
- Props/states:
  - **default**: value color `--amber-bright`, text-shadow `--glow-m`
  - **hot** (`.hot`): value color `--amber-hot` (`#ffe6c2`), text-shadow `--glow-l` — used for the hero numbers (speed, battery %, power kW, current/maxKw big values)
  - **warn** (`.warn`): value color `--red` (`#ff3b2f`), red glow — used for over-temp
  - **ghost** on/off: ghost backdrop is ON for large hero numbers only; OFF for all small/secondary numbers (Ah, range, current, max, and the whole bottom row), because the leading-digit ghost looked like an artifact on short values.
- Ghost text = value with every digit replaced by `8`.

### `SegBar` — vertical segmented bar gauge
- Column of N equal cells (default 16), `flex-direction: column-reverse` so it fills from the bottom, `gap 4px`.
- Cell off: background `--amber-dim`, radius 2px, subtle inset border.
- Cell on: background `linear-gradient(90deg, --amber-deep, --amber)`, glow-s + inner highlight.
- Cell warn+on: red gradient (`#9c1500 → --red`) + red glow. `warnAbove` prop = % threshold above which lit cells go red.
- Lit count = `round(count * pct / 100)`.

### Labels
- `.lbl` — section/field labels: Chakra Petch 600, uppercase, letter-spacing .18em, color `--label`.
- `.unit` — unit suffixes: Chakra Petch 600, letter-spacing .08em, color `--label`.
- `.navitem` — top-bar items: Chakra Petch 700, letter-spacing .12em, nowrap; `.active` adds amber-bright + glow-s.

## Screen treatment (the "fx" overlay)
The whole panel (`.scr`) has:
- Background: near-black `--bg` (#0a0806) with two warm radial gradients (top-center orange wash + bottom warm glow).
- A non-interactive overlay (`.fx::after`, z-index 50) combining:
  - **Scanlines**: `repeating-linear-gradient(to bottom, transparent 0 2px, rgba(0,0,0,0.16) 2px 3px)`
  - **Vignette**: `radial-gradient(130% 100% at 50% 50%, transparent 55%, rgba(0,0,0,0.55) 100%)`
- `-webkit-font-smoothing: antialiased`, `user-select: none`.

## Interactions & Behavior
This is currently a **static mockup** with sample values. For the real device, drive these from VESC telemetry:
- **speed** → hero number (km/h, zero-padded to 2 digits)
- **battery %** + **Ah used** + **range (km)** → battery column + left bar (bar = battery %)
- **power kW** + **current A** + **max kW** → power column + right bar (bar = power/maxKw %, red above 80%)
- **voltage, trip, odo, motor temp, controller temp** → bottom row
- **temps** flip to red/warn when > 70 °C (threshold is illustrative — set to the real safe limit).
- **clock** + **trip timer** → top bar.
- Top-bar items (`VESC MODE / STATISTICS / SETTINGS`) are placeholders for navigation to other screens (not yet designed).

Suggested polish for implementation (not in the mock): animate numeric changes, ease bar fills, smooth glow. Keep updates ≤ a few Hz to avoid flicker on the embedded panel.

## State Management
Minimal — a single telemetry object updated from the controller. Shape (see `DATA` in `variant-classic.jsx`):
```
{ speed, mode, batPct, batAh, range, powerKw, current, maxKw,
  voltage, trip, odo, mTemp, cTemp, clock, tripTime }
```

## Design Tokens

### Colors
| Token | Value | Use |
|---|---|---|
| `--bg` | `#0a0806` | screen background |
| `--bg-panel` | `#100b07` | panel background |
| `--amber` | `#ff7a1a` | primary amber (bars, accents) |
| `--amber-bright` | `#ffb35c` | default lit digit |
| `--amber-hot` | `#ffe6c2` | hero digit (hottest) |
| `--amber-deep` | `#c8470a` | gradient base for lit bar cells |
| `--amber-dim` | `rgba(255,122,26,0.09)` | unlit segment ghost / off bar cell |
| `--amber-dim2` | `rgba(255,122,26,0.16)` | faint fills |
| `--grid-line` | `rgba(255,122,26,0.14)` | dividers / borders |
| `--red` | `#ff3b2f` | warn / over-temp |
| `--label` | `rgba(255,176,110,0.55)` | labels & units |
| `--label-dim` | `rgba(255,176,110,0.35)` | idle labels |
| Bluetooth blue | `#2aa9ff` | BT dot + label |

### Glows (text-shadow / drop-shadow)
| Token | Value |
|---|---|
| `--glow-s` | `0 0 6px rgba(255,122,26,.55), 0 0 16px rgba(255,90,0,.35)` |
| `--glow-m` | `0 0 10px rgba(255,138,30,.6), 0 0 30px rgba(255,90,0,.4)` |
| `--glow-l` | `0 0 16px rgba(255,150,40,.7), 0 0 50px rgba(255,90,0,.45), 0 0 90px rgba(255,70,0,.25)` |
| warn glow | `0 0 10px rgba(255,59,47,.7), 0 0 28px rgba(255,40,0,.4)` |

### Typography
- **Numeric / readouts:** `DSEG7 Classic` (7-segment LCD font). Source used in mock: `@fontsource/dseg7-classic` (weights 400 & 700). On device, embed an equivalent 7-segment font. Fallback `monospace`.
- **Labels / UI:** `Chakra Petch` (Google Fonts), weights 400/500/600/700.
- Sizes (px): hero speed **166**; section big values **46**; secondary values **24–26**; section labels **22**; bottom labels **14**; unit suffixes **14–22**; top-bar **17**.
- Letter-spacing: labels .18em, SPEED label .32em, mode .3em, nav .12em.

### Spacing / layout
- Bands: 50 / 340 / 90 px. Side columns 210px each, center flexes.
- Column padding `16px 18px 10px`. Bar cell gap 4px, cell radius 2px.
- Borders/dividers all `1px solid --grid-line`.

### Sample data (placeholder telemetry)
`speed 42 (SPORT) · battery 73% · 6.4 Ah · range 38 km · power 2.8 kW · current 24.5 A · max 4.5 kW · voltage 58.4 V · trip 12.6 km · odo 6436 km · motor 47 °C · controller 39 °C · timer 0:48:12 · clock 14:32`

## Assets
- `reference_original_display.png` — photo of the stock VESC display this layout mirrors.
- `reference_cyberpunk_style.png` — the cyberpunk amber style reference the look is based on.
- Fonts are loaded from CDN in the mock (Google Fonts: Chakra Petch; jsDelivr: DSEG7). For the device, **bundle** both font files locally — do not rely on the CDN.

## Files in this bundle
- `VESC Dashboard (Variant A).html` — standalone, self-scaling reference page. Open in a browser to see the target. (It letterboxes the fixed 800×480 panel to fit the window.)
- `variant-classic.jsx` — the React/Babel source for Variant A and its primitives (`Seg`, `SegBar`, `BottomRow`, `Topbar`). This is the authoritative structural reference.
- `styles.css` — all design tokens, the 7-seg/ghost treatment, bar styles, and the scanline/vignette overlay.

> Note: `variant-classic.jsx` also exports two unused primitives (`SegRow`, `SmileArc`) and a `DASH` bundle that other (non-included) variants consumed. `SmileArc` is the removed speed arc — ignore both unless you want them.

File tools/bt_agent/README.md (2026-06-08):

# Bluetooth Classic Agent (D1 Mini ESP32-WROOM-32)

Standalone ESP-IDF project that runs on a **D1 Mini ESP32** (or any
ESP32-WROOM-32-based board) and acts as the Classic Bluetooth front-end for
the ESP32-P4 Android Auto head unit. It exists to defeat the modern
"Cakewalk" wireless-AA flow that Google rolled out in late 2023, which
silently blocks projection to head units that haven't gone through a real BT
pairing handshake.

## Wiring to the Waveshare ESP32-P4 board

J3 header on the bottom edge:

```
D1 Mini side             ESP32-P4 (J3)
─────────────────────────────────────────
GPIO 1 (TX0)    ────►    GPIO 21  (RX)
GPIO 3 (RX0)    ◄────    GPIO 22  (TX)
GND             ────     GND
5V (or VBUS)    ◄────    5V
```

The agent talks over **UART0** (the standard USB-Serial pins, GPIO 1/3).
The UART2 pads (GPIO 16/17) didn't reliably drive a 3.3 V signal on this
D1 Mini clone — on some clones those pins route to the CH9102 auto-program
circuit — so UART0 is the only path that moves data in both directions.
Trade-off: the on-board CH9102 USB-to-UART bridge shares these lines, so
the USB console and the P4 link both ride GPIO 1/3.

GPIO 21/22 on P4 are free expansion pins, so the USB-C debug console on P4
(GPIO 37/38) stays usable while the agent is wired up.

## Build & flash

The agent's UART link to P4 rides the same GPIO 1 (TX0) / GPIO 3 (RX0)
pins as the on-board CH9102 USB-Serial bridge, so the wires to P4 and the
USB-C cable fight over those lines. Flash in this order:

1. unplug the wires from P4 (GPIO 1 / GPIO 3 / GND / 5V)
2. plug in USB-C, run `idf.py flash` below
3. unplug USB-C, reconnect the wires to P4

Plug the D1 Mini into your laptop via its **USB-C** port. Find the serial
port (usually `/dev/cu.usbserial-XXXX` on macOS), then from this directory:

```
. ~/.espressif/v5.5.3/esp-idf/export.sh   # or wherever IDF lives
idf.py set-target esp32                   # only first time
idf.py -p /dev/cu.usbserial-XXXX flash monitor
```

First build pulls some BT components and is slow (couple of minutes).
Subsequent builds are quick.

## What you should see in the monitor

Boot output:

```
I (NNN) bt_agent: BT classic + SPP up. Discoverable as 'ESP32-P4 AA' (Car Audio)
```

Then on the phone, go to `Settings → Bluetooth → Pair new device` and you
should see **ESP32-P4 AA**. Tap it, accept the pairing prompt. The monitor
should print:

```
I (NNN) bt_agent: SSP confirm req num=... — accepting
I (NNN) bt_agent: auth ok with '<phone-name>'
I (NNN) bt_agent: SPP client connected: handle=...
I (NNN) bt_agent: TX msg=1 payload=N bytes        (WifiStartRequest)
I (NNN) bt_agent: RX msg=2 payload=0 bytes        (WifiInfoRequest)
I (NNN) bt_agent: TX msg=3 payload=N bytes        (WifiInfoResponse)
```

After the WifiInfoResponse, Android Auto on the phone should auto-launch
and try to connect to the P4 head unit at the IP/port we advertised.

## Configuration

`main/main.c` has hard-coded credentials at the top:

- `HU_WIFI_SSID` / `HU_WIFI_PASS` — the LAN credentials to hand to the
  phone. Must match what `main/bench_wifi.h` on the P4 contains.
- `HU_LAN_IP` — IP the P4 currently has (DHCP-assigned). Hard-coded for
  now; future revision will receive it from P4 via UART.
- `HU_LAN_PORT` — TCP port the AAP receiver listens on (5288).

## UART signals to P4 (for future P4-side coordination)

Single line per event, ending in `\n`:

| Line | Meaning |
|---|---|
| `BT:BOOT` | Agent just powered on |
| `BT:READY` | SPP server up, waiting for phone |
| `BT:PAIRED` | Phone completed Classic BT auth |
| `BT:CONNECTED` | Phone opened the SPP/RFCOMM channel |
| `BT:WIFI_INFO_SENT` | Sent WifiInfoResponse with creds |
| `BT:WIFI_CONNECT_STATUS` | Phone reported WifiConnectStatus |
| `BT:DISCONNECTED` | SPP channel closed |

P4 doesn't need to read these for the BT pairing experiment to work, but
they're useful for the eventual Mode A coordination layer.

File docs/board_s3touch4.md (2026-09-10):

# Waveshare ESP32-S3-Touch-LCD-4 (`s3touch4`)

The dashboard-only board: same firmware tree, same VESC dashboard, no Android
Auto. Written down here because the two hardware revisions differ in a way that
looks like a dead display if you guess wrong.

## Module and panel

| | |
|---|---|
| MCU | ESP32-S3-WROOM-1-N16R8 — dual Xtensa @240 MHz, 512 KB SRAM, 16 MB flash, 8 MB **octal** PSRAM |
| Panel | 4", 480×480, ST7701, RGB565 over the 16-bit RGB bus; controller registers over a 3-wire SPI link during init only |
| Touch | GT911, I²C, address 0x5D (0x14 on some units) |
| Radio | on-chip Wi-Fi + BLE 5 — no ESP32-C6, no ESP-Hosted |
| Console | USB-C is the chip's native USB (USB-Serial-JTAG), not a bridge chip |

## Pins

Shared I²C bus: **SDA GPIO15, SCL GPIO7** — touch, the PCF85063A RTC (0x51) and
the board helper all hang off it.

```
RGB   DE 40   VSYNC 39   HSYNC 38   PCLK 41
      B0-B4   5, 45, 48, 47, 21
      G0-G5   14, 13, 12, 11, 10, 9
      R0-R4   46, 3, 8, 18, 17
LCD   3-wire SPI: CS 42, SCL 2, SDA 1     (init only)
SD    1-bit SDMMC: CLK 2, CMD 1, D0 4     (shares CLK/CMD with the LCD link)
CAN   TX 6, RX 0        (TJA1051 on the external header)
RS485 TX 44, RX 43      (not used by this firmware)
```

The SD card and the LCD's control link share GPIO 1 and 2. The ST7701 only
needs that link while it is being initialised, so the card must not be mounted
before `bsp_display_new()` has run — which is the order the firmware boots in.

## Hardware revision — check before flashing

| | V4.0 | V3.0 |
|---|---|---|
| Helper on I²C | CH32V003 at **0x24** | TCA9554 at **0x20** |
| Backlight | PWM, 0–255 (inverted duty) | enable pin only, on/off |
| Also driven | LCD reset, touch reset, system power, buzzer, battery ADC | LCD reset, touch reset, backlight enable |
| Kconfig | `CONFIG_BSP_S3T4_HW_V4` (default) | `CONFIG_BSP_S3T4_HW_V3` |

Tell them apart from the silkscreen, or by which address answers on the bus.
The BSP logs `no IO expander at 0x…` and names the wrong-revision case when it
cannot find the one it was built for. With the wrong revision selected the
panel typically comes up after a warm reset and stays black after a power
cycle, because nothing pulses its reset line.

On V3.0 the brightness slider in Settings degrades to a switch: any value above
zero is full brightness.

Vendor material (schematic, examples, the CH32V003 and RTC components) is at
<https://github.com/waveshareteam/ESP32-S3-Touch-LCD-4> — see CLAUDE.md for the
clone line.

## Memory budget

Internal RAM is the constraint, PSRAM is merely tight:

| | |
|---|---|
| Two 480×480 RGB565 framebuffers | 920 KB PSRAM |
| `.text` + `.rodata` copy (XIP from PSRAM) | ~2.5 MB PSRAM |
| Boot-log ring (`CONFIG_LOG_CAPTURE_SIZE_KB`) | 256 KB PSRAM |
| Notification icon cache, LISP buffers, album art | ~0.6 MB PSRAM |
| LVGL heap (all of it — `LV_MEM_CUSTOM` allocates from PSRAM) | rest |

`CONFIG_SPIRAM_FETCH_INSTRUCTIONS` + `CONFIG_SPIRAM_RODATA` are what keep the
RGB panel from tearing when something writes flash: the LCD's DMA reads its
framebuffer through the cache, and without XIP-from-PSRAM every NVS commit
would disable that cache. It costs the 2.5 MB above, which is why Wi-Fi OTA
falls back to streaming instead of staging the whole image, and why BLE OTA can
run out of PSRAM and ask you to use Wi-Fi instead.

## Bring-up checklist

1. Identify the revision (above) and set it in `menuconfig` if it is V3.0:
   `scripts/build_board.sh s3touch4 menuconfig` → Board Support Package.
2. `scripts/build_board.sh s3touch4 -p /dev/cu.usbmodem* flash monitor`.
3. In the boot log check: `spi_flash` reports 16 MB, `display_init` starts
   printing `render: N fps | avg …ms`, `wifi_manager` brings up the SoftAP,
   `comm_can` starts on TX 6 / RX 0.
4. Watch the panel while something writes flash (open Settings and change a
   value, or run an OTA): no tearing or sideways drift. If it does drift, the
   next lever is `CONFIG_BSP_LCD_RGB_BOUNCE_BUFFER_HEIGHT`, then re-arming
   `flash_shade` (see `main/display_init.c`).

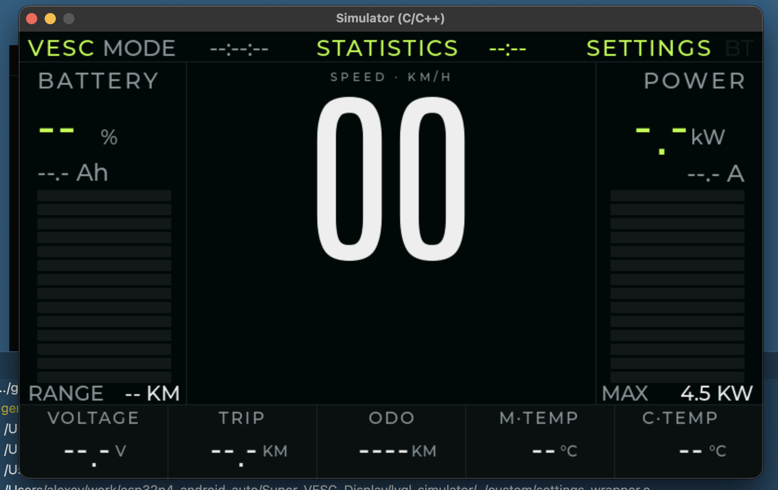
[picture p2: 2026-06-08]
Super_VESC_Display/design_handoff_vesc_dashboard/reference_cyberpunk_style.png

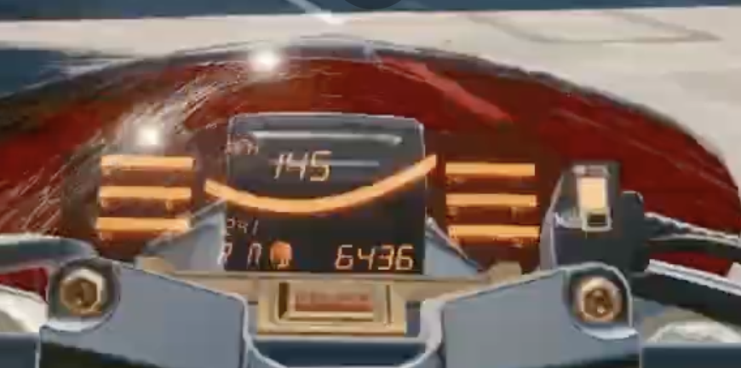
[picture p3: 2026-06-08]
Super_VESC_Display/design_handoff_vesc_dashboard/reference_original_display.png

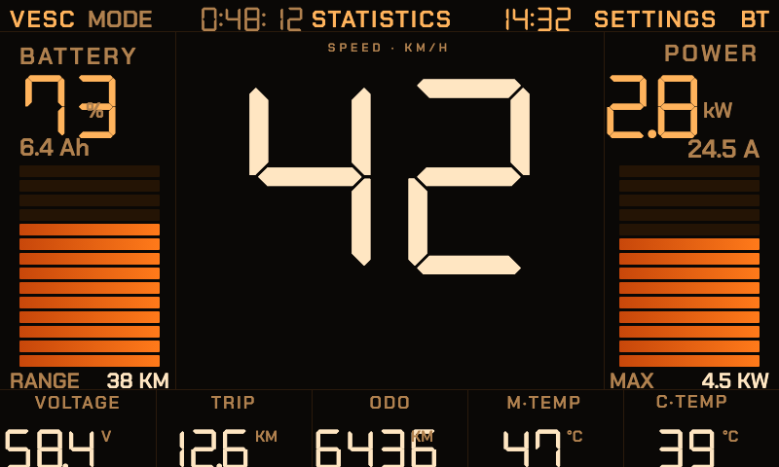
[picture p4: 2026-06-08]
Super_VESC_Display/design_handoff_vesc_dashboard/amber_dashboard_preview.png

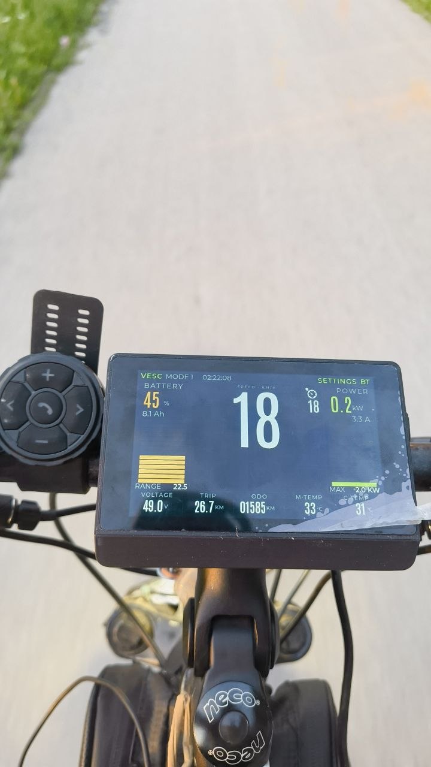
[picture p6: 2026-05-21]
docs/images/vesc-hud.jpg

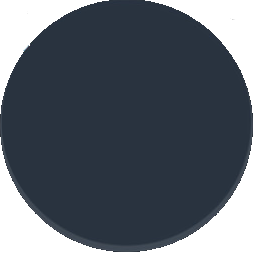
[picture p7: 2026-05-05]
Super_VESC_Display/import/image/speed_background.png

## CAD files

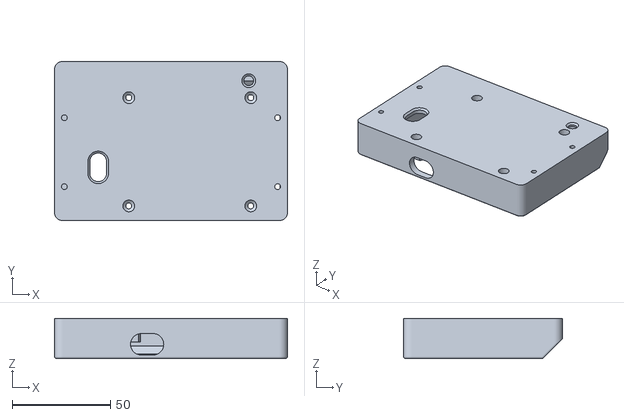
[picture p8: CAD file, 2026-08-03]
3d-model/esp32-p4-wifi6-guiton-800x480/main.stl
118.4 x 80.8 x 20.5

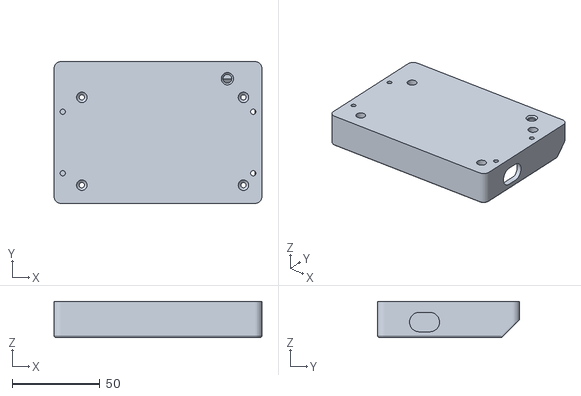
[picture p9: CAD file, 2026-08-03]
3d-model/esp32-p4-wifi6-waveshare/main.stl
118.4 x 80.8 x 20.5

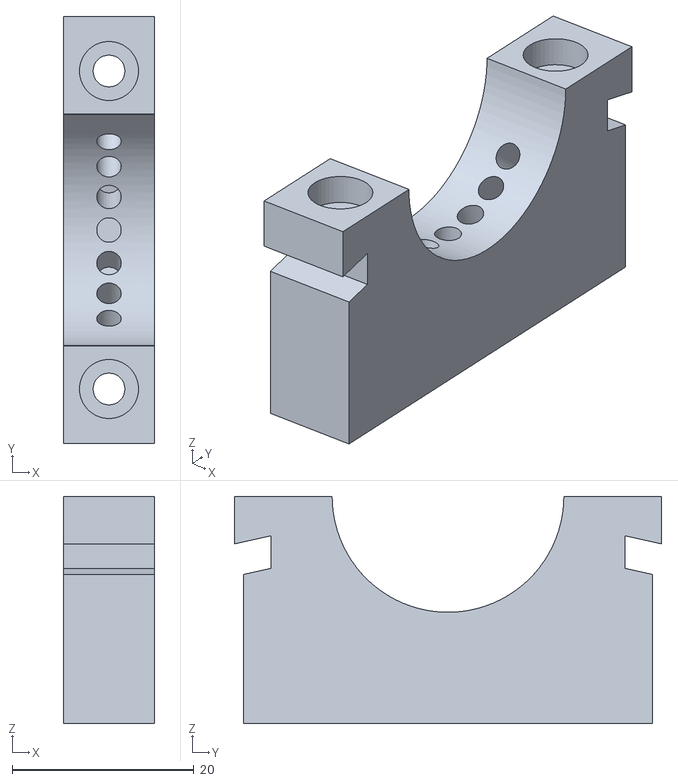
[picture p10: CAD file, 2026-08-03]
3d-model/esp32-p4-wifi6-guiton-800x480/u-holder.stl
10.0 x 47.0 x 25.0

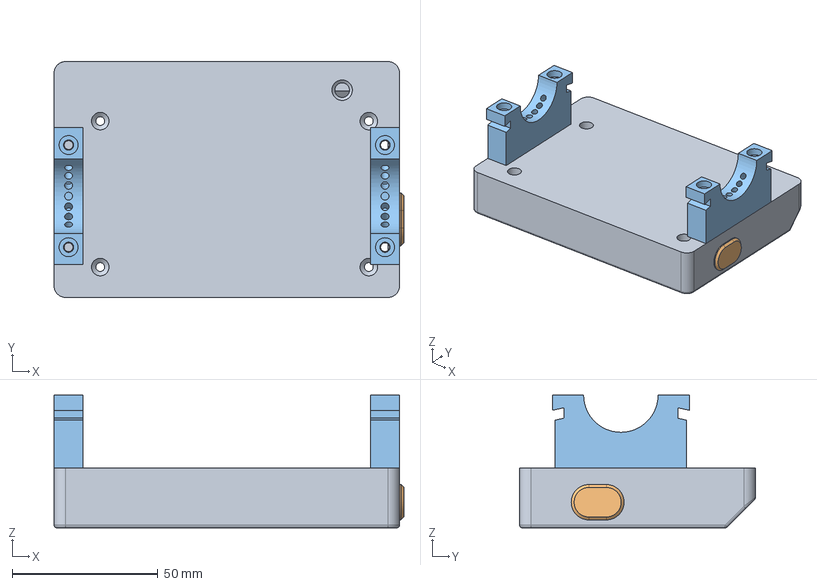
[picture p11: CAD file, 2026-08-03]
3d-model/esp32-p4-wifi6-waveshare/esp32-p4-wifi6-waveshare-800x480.step
119.9 x 80.8 x 45.5 mm
Main
cover-TPU
u-holder x 2
insert

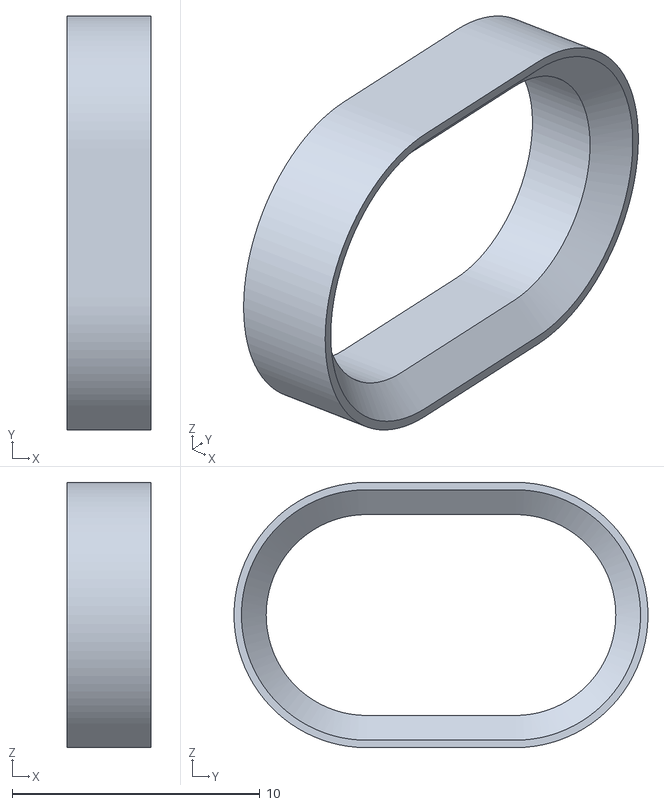
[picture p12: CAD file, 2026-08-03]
3d-model/esp32-p4-wifi6-waveshare/insert.stl
3.40 x 16.7 x 10.7

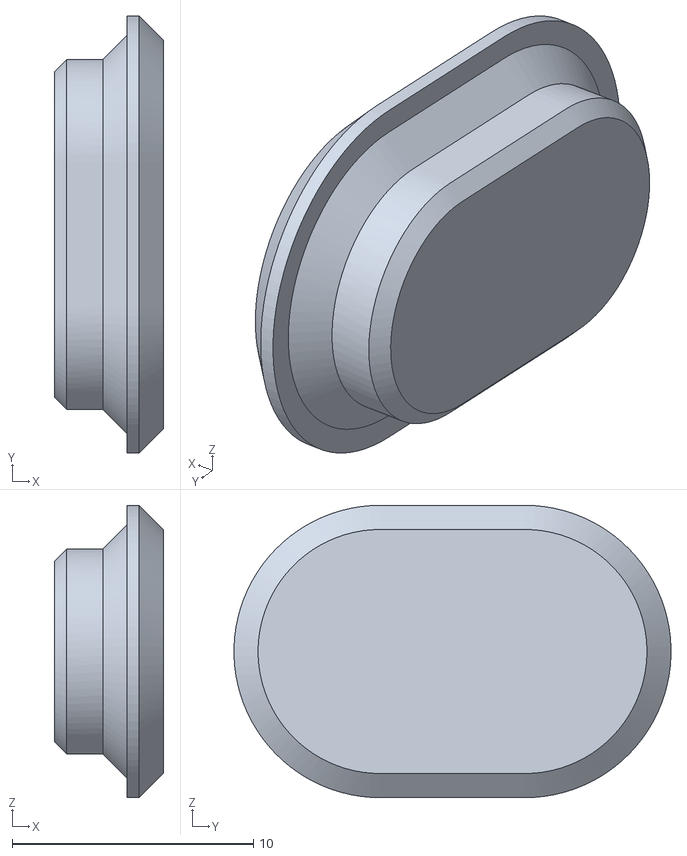
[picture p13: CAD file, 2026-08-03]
3d-model/esp32-p4-wifi6-guiton-800x480/cover-TPU.stl
4.50 x 18.1 x 12.1

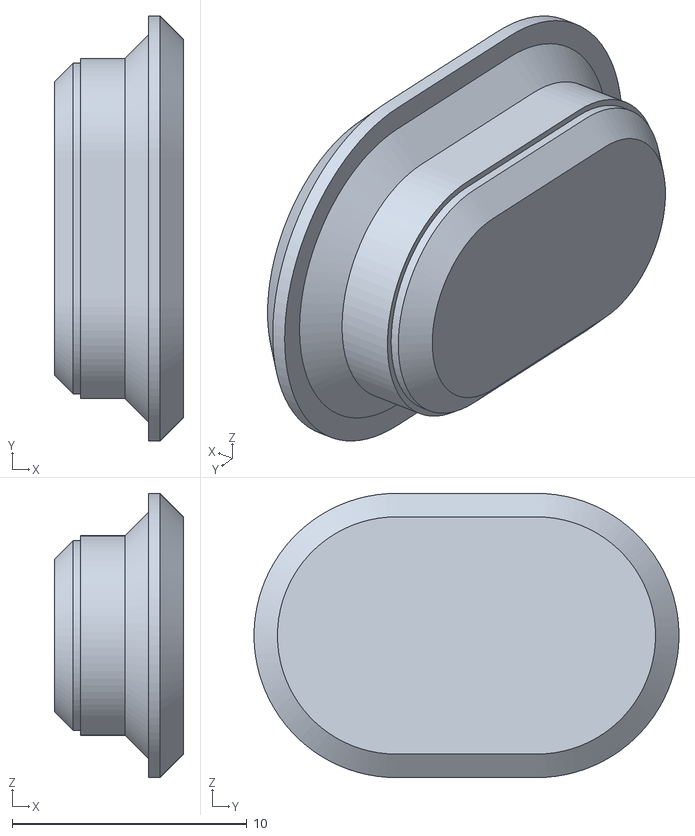
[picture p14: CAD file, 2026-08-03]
3d-model/esp32-p4-wifi6-waveshare/cover-TPU.stl
5.50 x 18.1 x 12.1

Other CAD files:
3d-model/esp32-p4-wifi6-guiton-800x480/esp32-p4-wifi6-guiton-800x480.step
3d-model/esp32-p4-wifi6-waveshare/u-holder.stl
3d-model/esp32-p4-wifi6-guiton-800x480/insert.stl

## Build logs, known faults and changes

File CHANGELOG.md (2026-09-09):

# Changelog

Two version trains ship together and are bumped in lockstep by
`scripts/release.sh`: the **ESP32-P4 firmware** (`1.x.y`, `version.txt`) and the
**Flutter companion app** (`0.x.y`, `pubspec.yaml`). The external BT-agent
firmware is versioned separately and is only bumped when `tools/bt_agent/`
changes.

Entries below name the firmware version; the app version of the same release is
the one recorded in the release commit.

## v1.3.17 / app 0.3.17 — 2026-09-09

### Waveshare microphone actually works

- 1.3.16 shipped the Android Auto microphone dead on the Waveshare 4.3: the
  two MEMS mics sit on ES7210 inputs MIC1 and MIC3 (MIC2 is the echo-cancel
  reference fed from the speaker output, MIC4 is unconnected), while the code
  read MIC1/MIC2 as a plain I2S stereo pair — a mode in which MIC3 never
  reaches the ESP32-P4 at all. Found by tapping the mics with all four inputs
  captured at once; only ADC1 and ADC3 moved. The ADC is now driven the way
  Waveshare's own demo does it (three inputs selected, which puts the chip in
  TDM so all four channels arrive on one line), the two mics are averaged
  into the mono stream, and the input gain went from 24 to 30 dB. Guition
  JC4880 (ES8311 ADC) is unchanged and worked already.

### Touch

- Android Auto ignores contacts shorter than 250 ms: a press is reported to
  the phone only once the finger has stayed down that long (at the touch-down
  point, then caught up to where the finger is), and a shorter contact sends
  nothing. Stops vibration, knuckles and raindrops from tapping things;
  fast flicks under the threshold are lost — deliberate.
- Groundwork for a smaller Android Auto viewport inside the 800×480 frame
  (video margins): touch is reported relative to the phone's content area and
  the touch-screen descriptor advertises that area. Margins ship at 0×0, so
  nothing changes on screen.

## v1.3.16 / app 0.3.16 — 2026-09-07

### Microphone to Android Auto

- The head unit's own microphone now feeds the Android Auto voice input. The
  phone has been asking for it all along (AVInputOpenRequest on the mic
  channel, previously logged as "not handled") — the request is now answered
  and, while a voice session is open, the on-board mic is streamed as
  16 kHz / 16-bit / mono PCM in 40 ms chunks. Gives Google Assistant voice
  input through the unit; the spoken reply still plays on the phone because
  the Speech audio channel is not advertised. Phone calls are unaffected
  (they ride Bluetooth HFP, which the BT agent does not do).
- Waveshare 4.3: MIC1 of the two on-board MEMS mics via the ES7210 ADC.
  Guition JC4880: mic on the ES8311's own ADC, compile-only. Kconfig
  `AA_MIC_ENABLE` (default on) removes the whole path — the phone then gets
  an "open failed" answer instead of silence.

## v1.3.15 / app 0.3.15 — 2026-09-06

Curated Android Auto branch: only the fixes and the changes that showed a
clear effect, without the experimental in-tree decoder. Not the 1.3.12-1.3.14
line (that stays on the video-perf branch).

### Android Auto reconnect and the Connect button

- A dropped session no longer strands the head unit. The socket gained TCP
  keepalive and receive/send timeouts, so a phone that leaves the AP silently
  (out of range, pocket) is noticed within ~15 s instead of hanging the session
  forever. A clean goodbye (ByeBye) is told apart from a lost link, and the
  phone is given a 3 s grace to restart projection on its own before the head
  unit kicks it off the AP.
- The BT agent leaves the air for the whole session (agent 0.6.4 -> 0.6.6),
  the way the reference dongles power their radio off, so a stray Bluetooth
  event can no longer make the phone restart projection mid-ride.
- **Connect now works.** Two dead paths fixed in agent 0.6.7: the phone it
  pages is the one that last ran Android Auto (not whichever paired last), and
  a Connect tap with the link half-up but no session tears it down so the phone
  re-runs the wireless setup instead of doing nothing.
- Agent updates no longer wipe the agent's own pairing. The OTA used to erase
  the agent's NVS on every write, so after each update the phone had to be
  re-paired; it now skips the NVS region.

### Screen

- The Android Auto idle screen shows the link state — Disconnected /
  Connecting... / Connected — in colour, with the step in progress as the
  subtitle and the IP / port on a dim third line.
- The backlight goes dark during flash erases and bulk writes instead of
  letting them tear the panel blue, and comes back a moment after the last one.
- The LVGL worker no longer busy-spins on core 0; it was starving Bluetooth and
  the idle task badly enough to trip the watchdog.
- A touch is ignored for 1 s after a dashboard <-> Android Auto switch so a
  stray finger doesn't land on the wrong screen.
- Boot-time "battery charged — reset trip?" prompt: the dashboard asks before
  resetting the trip instead of doing it silently.

## v1.3.11 / app 0.3.11 — 2026-09-02

### Faster firmware updates over Bluetooth

Why a BLE update took 10+ minutes: a 4.4 MB image went out as ~18 000
writes of 244 bytes, the phone stack issues them one per ATT round trip, and
four things kept each round trip slow:

- **Connection interval.** Nothing asked for a fast link, so the transfer ran
  at Android's default ~45 ms interval. The LISP editor already requests
  high priority (7.5–15 ms) for its transfers; the OTA path did not. Now the
  app requests it for the duration of the update, and the firmware asks from
  its side too on BEGIN (`ble_gap_update_params`, 11.25–15 ms — Android
  refuses anything shorter), reverting on failure.
- **Sensor initiator scan.** With a PAS or wheel-speed sensor bound but asleep
  (the usual state of a parked bike), the head unit keeps a connect attempt
  pending — and NimBLE's default connect parameters scan for the peer at
  100 % duty, sharing the radio with the phone link the whole time. The
  arbiter now scans 30 ms in every 100 ms (a sensor advertising at ~1 Hz is
  still caught within seconds of waking), and the OTA parks the arbiter
  entirely while receiving.
- **Chunk size.** The firmware's flatten buffer capped DATA writes at 244 B
  although both sides negotiate MTU 512. The buffer now takes 509 B and READY
  advertises that cap in its `detail` field; the app uses the largest chunk
  the cap and the MTU allow — half the writes. Older firmware sends 0 and the
  app keeps 244.
- **Ack fallback.** On Android's BUSY (TX credits exhausted) the app retried
  after 15 and 30 ms and then switched that chunk to an *acknowledged* write
  — one chunk per connection event. Under load that path swallowed most of
  the image. Retries now wait roughly a connection interval and stay
  unacknowledged for six attempts before falling back.
- Also: progress IPC to the UI isolate is throttled (was one message per
  chunk).

Note: the update *to* 1.3.11 still runs on the old firmware's side of the
protocol (244-byte chunks, no peripheral-side interval request, scan still
running) — only the app-side improvements apply to it. Updates *from* 1.3.11
onward get the full effect. Not hardware-measured yet.

## v1.3.10 / app 0.3.10 — 2026-09-02

### Android Auto no longer drops on a big video frame

- Field log (1.3.9, five minutes into a session): `aa_tls: decrypt: out_buf
  full (1564)` → `recv_decrypted: ESP_ERR_NO_MEM` → `tcp: client closed` —
  the panel fell back to the dashboard and the phone had to reconnect. A
  fragmented AA message (a video I-frame) came in larger than the fixed
  96 KiB reassembly buffer. The same cap had already been raised once, from
  32 KiB, for the post-BT-handover key-frame burst.
- `recv_decrypted` now reassembles into per-channel buffers that grow on
  demand (doubling from 96 KiB, hard ceiling 2 MiB — an 800×480 I-frame is
  ~100–300 KiB) and hands the message to the dispatcher by pointer instead
  of copying it out, which also removes a ~100 KiB memcpy per video frame.
  Growth steps are logged once (`ch 3 reassembly buffer 98304 -> 196608
  bytes`) so real frame sizes show up in the log.

### Trip statistics switch removed again

- The opt-in switch introduced in 1.3.9 is gone; statistics are always on,
  as before 1.3.9 (the NVS key it left behind is ignored). What stays from
  1.3.9 is the actual fix: the trip log's sector runway is erased at boot,
  before the display comes up, instead of at every stop longer than ~30 s.
- On the log's own device the runway was already clean (`runway: 64 clean
  sectors ahead`) — so the stop-time erases were NOT what that unit was
  freezing on; the 10 s record writes remain the only flash activity during
  a ride.

## v1.3.9 / app 0.3.9 — 2026-09-02

### Trip statistics are now opt-in (Settings → Trip statistics, default OFF)

- New switch **Settings → Trip statistics**. Off (the default): the dashboard's
  STATISTICS entry point is hidden on every theme and the trip log does
  nothing at all — no boot scan, no 10 s record writes, no sector erases, no
  flash I/O. On: behaves as before; toggling takes effect without a reboot
  (off stops sampling and erases at once, on scans the ring and starts a new
  trip). The Settings "Reset" button returns it to off.
- Why: every flash write or erase on this board suspends the cache for both
  cores AND stalls the DSI DMA that feeds the panel from PSRAM (AUTO_SUSPEND is
  unavailable on this GD25Q256, see `sdkconfig.defaults`), so the trip log was
  the one subsystem that touched flash *during a ride* — a 64-byte record
  every 10 s, plus 4 KB sector erases (45–400 ms each = a frozen screen with a
  blue flash) whenever the runway of pre-erased sectors ahead of the log's
  head had to be rebuilt. It is the prime suspect for the "dashboard freezes
  for a moment, often" reports. With the switch off a ride performs zero flash
  writes; if the freezes persist with it off, the cause is elsewhere (CAN data
  dropouts, render path) — the switch doubles as the experiment.
- Consequence of "off": the dashboard TRIP / Ah / uptime totals no longer
  survive a head-unit reboot (the log was their only persistence) and start
  from zero at every power-on; the smart-battery tracker falls back to its
  10-minute NVS backup. The odometer is unaffected (it comes from the VESC, or
  from the BLE speed sensor's own NVS counter).
- Firmware side (`components/trip_log`): the old boot scan never *cleaned*
  anything — at start it only read one record per sector to find the head and
  erased 2 sectors ahead; old trips were left for the ring to overwrite, and
  the erases of that stale data ran from the writer's idle loop, i.e. at every
  stop longer than ~30 s (one 45–400 ms freeze every 3 s until 64 sectors were
  clean), or just-in-time mid-ride once the runway ran out. Now, when the
  feature is on, the runway is rebuilt synchronously in `trip_log_init()`
  BEFORE `display_init()` — the panel is still dark, so a dirty sector costs
  boot time (typically a few sectors ≈ 0.1–0.3 s; capped at 3 s, the rest is
  left to the idle trickle) instead of a mid-ride freeze. The idle trickle and
  the just-in-time erase remain as fallbacks only.
- Not hardware-verified: the freeze diagnosis itself. Compile-tested on
  Waveshare + the desktop simulator.

## v1.3.8 / app 0.3.8 — 2026-08-19

### BLE wheel-speed sensor (stock Coospo-class CSC sensors)

- The head unit can now take its speed from an off-the-shelf BLE wheel-speed
  sensor (Coospo, Magene, ... — anything speaking the standard Cycling Speed
  and Cadence profile, service `0x1816` / CSC Measurement `0x2A5B`). New
  files: `main/ble_speed_client.c` (central client + wrap/reset-safe CSC
  parser), `main/speed_sensor.c` (source setting, rev→km/h conversion, local
  trip/odometer integrators + their NVS persistence in namespace `spdsns`),
  `custom/speed_screen.c` (settings screen).
- **Settings → Speed sensor → Open**: pick the speed source (VESC vs BLE
  sensor — an explicit switch, no auto-fallback), pair/forget the sensor
  (same address-binding flow as the PAS cadence sensor), set the wheel
  diameter (the shared `wheel_mm` setting, now with a debounced NVS commit so
  +/- taps don't stall LVGL), and watch live speed / trip / odometer /
  sensor battery.
- With the BLE source selected, dashboard **speed, trip and odometer** come
  from wheel revolutions × circumference — they keep updating even when the
  VESC is silent (the "ESC NOT CONNECTED" banner still reflects the VESC).
  The AA video HUD speed and the trip-log speed samples follow the same
  source; the trip-log idle detector (which gates flash-erase trickling)
  now requires BOTH sources to look idle before erasing. The local odometer
  is stored in NVS (saved on ride stops + a 10 min fallback, on a dedicated
  writer task) and is never resettable; "Reset trip" zeroes the BLE trip
  alongside the VESC one.
- Both BLE sensors (cadence + speed) can be bound at once: a new
  `main/ble_central_arb.c` shares NimBLE's single connect-initiator between
  them (one bound sensor behaves exactly as before; with two, connect
  attempts rotate on 8 s windows). `CONFIG_BT_NIMBLE_MAX_CONNECTIONS` is now
  4 — delete the stale per-board `build_*/sdkconfig` before rebuilding.
- NOT yet hardware-verified: CSC parsing against a real Coospo, dual-sensor
  coexistence, and the BLE-source trip/odometer accuracy.

## v1.3.6 / app 0.3.6 — 2026-08-05

### One navigation strip across the on-device web UI

- The three built-in pages — `/ota` (firmware update), `/files` (file manager)
  and `/lisp` (LISP editor) — now share an identical tab strip, so they read as
  one interface instead of three unrelated pages. Markup and CSS live in
  `main/web_nav.h`; the current tab is marked by appending `on` to its class.
- No JavaScript: every tab is a plain link to a sibling page, which costs
  nothing and survives a reload.
- The LISP editor is a standalone gzipped `.html` and cannot include a C
  header, so it carries its own copy of the strip — the header says so, and the
  two have to be kept in step by hand.

### Line-by-line Russian walkthrough of the LISP script

- `lisp/main.ru.lisp`: the same code as `main.lisp` with an explanation above
  every line. Documentation only — **`main.lisp` is what gets flashed**, and
  this copy has to be updated by hand when the real script changes.

## v1.3.5 / app 0.3.5 — 2026-08-05

### The display no longer dies on the CAN bus (and neither does the helper)

- `comm_can.c` never handled **TWAI bus-off**. Past 255 transmit errors the
  controller stops, and it does not come back on its own: recovery has to be
  requested, and after 128 sequences of 11 recessive bits the driver waits in
  STOPPED for an explicit start. Without those two calls a node that hit bus-off
  was simply gone from the bus until its power was cycled — every send returned
  silently, with nothing in the log.
- Found while chasing dead pedal assist: the **C3 BLE helper** lost PAS, the
  throttle toggle and its state queries all at the same instant, and only a
  power cycle brought them back. Same bug, same file — the helper's fix ships as
  its `v1.0.8`.
- `can_health_check()` now runs every 500 ms from the receive task (which
  already wakes on a 10 ms timeout, so no new task): bus-off → recovery,
  STOPPED → restart, both logged.

### Why the bus gets there

A trace of the wire counted **35 615 bus errors** with our own
`tx_error_counter` pinned at 128, on a 1 Mbit/s bus with three nodes. Recovery
removes the permanent death, not the errors. If the recovery counter climbs in
normal use, the bus itself wants attention — 500 kbit/s is the VESC default and
has twice the timing margin.

### CAN polling hold-off

- New `CONFIG_VESC_CAN_POLL_START_DELAY_MS`, default **4000**: the display stays
  off the bus for the first four seconds, while the other nodes and the VESC's
  LISP script come up. Cheap insurance, not the fix — note that it delays only
  the *polling*; the TWAI controller itself joins the bus at `comm_can_start()`
  and participates in ACK and error signalling from that moment.

### Bundled helper firmware

- Now **1.0.8** (was 1.0.6 in the 0.3.4 APK, which predated the helper release).
  `stage_firmware_asset.sh` pulls it from the helper repo's latest GitHub
  release at build time, so cutting this release after publishing the helper's
  is what keeps the two in step.

## v1.3.4 / app 0.3.4 — 2026-08-03

No firmware or app code changed in this repository — this release exists to ship
the enclosure models and to cut a numbered build of the current tree.

### Enclosure models for the Guition board

- `3d-model/esp32-p4-wifi6-guiton-800x480/` — main body, insert, u-holder and a
  TPU cover, plus the STEP source. The Waveshare models move into
  `3d-model/esp32-p4-wifi6-waveshare/`, so the directory now names its board
  instead of implying there is only one.

### Related: the PAS chain fix landed in the helper, not here

- The pedal-assist regression traced to the **C3 BLE helper** (separate repo,
  firmware `v1.0.7`): its single boot-time `REQ_STATE` missed while the VESC was
  still loading `main.lisp`, and with periodic polling off by design the miss was
  permanent — hence "no data from vesc" in the app, and a throttle toggle that
  flipped `throttle-on` from a guess, which coasts the motor arbiter
  (`lisp/main.lisp:451`) with a healthy cadence sensor.
- Nothing on the P4 side was involved, so this app build carries the same P4
  firmware as 1.3.3. The helper image is fetched from the helper repo's GitHub
  releases at update time, not bundled here.

## v1.3.3 / app 0.3.3 — 2026-08-03

### New: three concept dashboard themes

- **Classic Max**, **Lamborghini** and **Supermoto**, plus a reference screen,
  generated by the new `tools/build_classic_max.py` and
  `tools/build_concept_dashboards.py`.
- The amber dashboard is gone, and with it the DSEG7 / DSEG14 segment fonts: no
  screen references them any more, so they are neither compiled from
  `generated/guider_fonts` nor re-subset into the build. The `.ttf` files stay
  in `import/font/` and the CMake comment says what to re-add to bring them
  back. Antonio gains a size-100 subset.
- The simulator's `dashboard_themes_auto.c` is generated from `gui_guider.h` by
  `scripts/gen_dashboard_themes.py`, so it is now gitignored as a build artifact.

### The AI assistant can no longer ship a dead panel control

- Asked to add on-screen profile switching, the assistant emitted
  `(pu8 1) (pu8 8) (pstr "Profile")` — `<id>` and `<type>` swapped, so the type
  byte read 8. An unknown type has no known tail length, so the P4 stops
  decoding and throws away the **rest of the frame**: the row silently never
  rendered, with nothing but an `ESP_LOGW` on the head unit's own console to
  show for it. The protocol lived only in `lisp/README.md`, which the model is
  never shown, and the linter knew nothing about it — so the invariant was
  enforced nowhere.
- The prompt now carries the panel as a fails-silently section (id-then-type,
  the four control types, the count byte in both senders, one id across all
  three functions, the 16-control cap, and that a panel change is three edits),
  the full byte layout, copy-paste templates for all four types, and the
  radio-group pattern — there is no 1-of-N control, so a profile selector is N
  toggles over one variable.
- The linter gates flashing on nine new checks: unknown control type, a count
  byte that disagrees with the rows listed, duplicate ids, ids that only
  `panel-send-state` or `panel-action` know about, over-long labels and unit
  suffixes (a label ≥ 40 bytes leaves the P4 decoder stopped mid-string and
  everything after it is misread), and a frame wider than its `bufcreate`.
- False positives were the design constraint — a gate that cries wolf gets
  switched off, taking the real checks with it. An unrecognised shape produces
  **no** diagnostic: broken parens skip the pass, every emit in a frame must
  share one parent (so rows emitted inside an `if` or a loop are left alone), a
  foreign call between emits abandons the frame (helper emitters), and
  non-literal arguments disable only the rule that needed the value.
- Also written down for the model: why the arbiter ticks at 100 Hz (at 20 Hz the
  ramp advanced in 12.5 %-of-max steps that FOC executes instantly — the rider
  felt jerks) and why `app-disable-output` is refreshed every tick rather than
  once (if the script dies the stock throttle returns ~1.5 s later and the bike
  stays rideable).

### Pedal assist: one sender at a time

- Two nodes may stream PAS setpoints, and the head unit's own PAS idles at 0 A,
  20 Hz, forever. Interleaved with a real assist current those zeros chopped the
  setpoint into 3 A → 0 → 3 A and the motor jerked. The script now locks onto
  whoever sent the last non-zero setpoint and ignores the others until that
  source goes silent or sends zero; a 0.4 s staleness check releases the lock
  too.
- The BLE helper can toggle the throttle master switch atomically (`msg 0x06`,
  it never needs to know the current state), and its buttons arrive as plain
  standard-id CAN frames on `0x123` mapped to throttle-toggle and
  profile-switch.

## v1.3.2 / app 0.3.2 — 2026-08-02

### New: LISP editor in the browser

- `http://android-auto.local/lisp` — a full LispBM editor on the head unit's
  own HTTP server, next to `/ota` and `/files`. Syntax highlighting, line
  numbers, matching and rainbow parens, find/replace, block indent, hotkeys.
- The linter encodes the failures that cost the most time here: paren balance,
  unterminated strings, `@const-start` / `@const-end` pairing, defuns left
  outside the const block, buffers created inside it, and a thread started
  before the function it runs is defined (the handler dies with
  `variable_not_bound` and the feature is simply gone).
- Read VESC / Upload / Upload + Run / Start / Stop over CAN with a progress
  bar. The transfer is asynchronous — an upload takes tens of seconds and the
  server serves everything from one task, so blocking it would freeze `/files`
  and `/ota` too.
- Live console of the script's `(print ...)` output. The firmware never parsed
  `COMM_LISP_PRINT` / `COMM_PRINT` before; the packets were arriving all along.
- A REPL line evaluates an expression without reflashing the script (capped at
  240 bytes — one CAN buffer transfer).
- The script library on the device (`/vescfs/lisp` and microSD) is browsable
  from the same page: open, save, rename, **move**, delete, mkdir, upload.
- `scripts/lisp_web_mock.py` serves the page against a fake device, so the
  editor can be worked on without a board.

### CAN identity

- The head unit answers `COMM_FW_VERSION` on the bus, so VESC Tool's CAN scan
  lists it as **Super VESC Display** instead of "Unknown". It replies to that
  one request only — it is not pretending to be a motor controller (the scan
  icon comes from `HW_TYPE_CUSTOM_MODULE`).

### Traction control in the LISP arbiter

- The native VESC traction-control algorithm, ported into the arbiter as a
  0..1 current scale. It cannot be left to the ADC app: that app's control
  block sits behind `app_is_output_disabled()`, which the arbiter keeps
  asserted, so the app's own TC never runs.
- On/off and the threshold are the real appconf fields `adc-tc` /
  `adc-tc-max-diff` — the panel toggle, the on-device VESC Tool menu and VESC
  Tool itself are one setting. `tc-peer` (the other motor's CAN id) must be set
  by hand; 255 disables the limiter, which is the safe default.
- Profiles are now also selectable directly from the on-screen panel
  (`panel-set-profile`), a radio group of three. The tune/melody controls are
  gone, and with them the ~2 kB quoted literal that cost cons heap at load.

### Reference and docs

- `conf-get`'s second argument is a "read the firmware defaults" **flag**, not a
  fallback value, and `conf-store` writes both mcconf and appconf from live RAM
  — in a script that scales limits at runtime that bakes temporary values over
  the rider's master config. Both are now documented in the assistant's LISP
  reference and in `lisp/README.md`.

## v1.3.1 / app 0.3.1 — 2026-07-31

30 commits, 130 files, +27 929 / −8 284 since v1.2.35.

### New: AI assistant for LISP

- An "Assistant" tab in the LISP editor. It reads the script off the VESC,
  edits it with anchored search/replace patches, runs the linter, flashes only
  on an explicit tap, and then **verifies on hardware** — doneCtx, heap trend,
  sentinel globals, print output. The protocol acks only prove the bytes
  reached flash; they succeed even when the script is dead, so they are not
  trusted.
- Every flash and every script start needs a tap; stopping a script never does.
  Provider is OpenRouter (or DeepSeek directly), the key is yours and lives in
  the system keystore.
- A VESC LispBM reference ships in the prompt — motor commands, config, CAN,
  buffers, events — taken from the upstream bldc docs, plus this project's own
  rules and worked examples.

### New: ESP32-C3 BLE helper configurator

- Status, parameters, pairing and firmware screens: cadence gauge, assist
  current and levels, binding of buttons and the cadence sensor (the helper
  itself does the scanning), per-button CAN commands, PAS tuning.
- Runs as a second GATT link from the background isolate, so the head-unit
  connection stays up while you configure the helper.
- The helper's firmware is pulled from its GitHub releases at build time and
  bundled into the APK, so it can be flashed with no network.

### VESC console and LISP linter

- Script `(print ...)` output is finally visible on the phone. The bytes always
  arrived — the head unit's bridge forwards every packet — but the link layer
  dropped anything that matched no pending request.
- The linter encodes the rules that fail SILENTLY on hardware: one `@const`
  block, mutable `def`s and `bufcreate` above it, and no forward references
  from top-level statements (not "spawns last" — `main.lisp` legitimately
  spawns from the middle of its const block).
- Syntax highlighting in the editor and in the assistant's code blocks.

### LISP and motor control

- LISP editor in the app over any NUS link: the head unit's bridge, a
  stand-alone VESC BLE adapter, or the helper.
- Upload format now matches VESC Tool's CodeLoader. WRITE offsets include the
  8-byte flash header the VESC validates at startup, so raw uploads flashed
  fine and then never loaded. Limit raised 16K → 120K, pollers pause during a
  transfer, faster BLE reads.
- The motor is owned by a single current-based arbiter in LISP (100 Hz):
  smooth ramps, brake slew, no step to zero. The stock ADC app stays configured
  but its output is suppressed by a rolling `app-disable-output` — if the
  script ever dies the motor stops on the command timeout and the stock
  throttle comes back in ~1.5 s.
- Tuning moved out of the quick panel: ramp times are read live from VESC Tool,
  cruise PI gains live in the script.

### Pedal assist (PAS)

- Entirely on the head unit: a BLE central link to the cadence sensor, the PAS
  loop, and a current setpoint handed to the arbiter on the VESC. The phone is
  not involved.
- Quiet on CAN unless actually assisting. PAS_SET frames used to stream at
  ~20 Hz forever, even with no sensor connected.

### Display and settings

- 180° screen rotation for upside-down mounting, done at render level:
  panel-level mirroring on the ST7701 produces stripes because the DPI scan
  order is fixed — the data has to be flipped, not the panel.
- Hold-to-repeat on the +/− step buttons in settings.
- "Display CAN ID" row — the head unit's own CAN node id. The backend existed;
  its UI had been left commented out.
- throttle-curve range corrected to −100..100%. An audit of 985 parameters
  across three firmware versions found this to be the only display-range
  divergence.

### BLE and stability

- Advertising continues while a peer is connected, so VESC Tool can find the
  head unit alongside the phone app. The third NimBLE slot stays reserved for
  the cadence sensor.
- The NUS→CAN bridge targets the VESC id from settings instead of a
  compile-time default. Anyone whose VESC sits on a different CAN id had a
  working dashboard but VESC Tool over BLE timing out against a node that does
  not exist.
- No more screen stalls while riding: the battery tracker's NVS commits moved
  off the LVGL thread and the trip log is trickled out over time.
- The app's whole BLE stack moved into the foreground-service isolate;
  reconnect hardened.

### Tooling

- `scripts/build_app.sh` builds the APK with **no embedded API key** by
  default; `--with-key` masks the key from `.env` into the build.
- `scripts/release.sh` aborts if a key ends up in the APK anyway. The check
  reads the decompressed zip entries — grepping the `.apk` itself always
  reports "clean" even when the key is sitting in `libapp.so`.
- `scripts/build_board.sh` uses each build directory's own Python venv, so both
  boards build in one run. Releases used to stop at the first board.

## Earlier releases

Shipped between v1.2.35 and v1.3.1; cut as release commits but not tagged.

| Version | Date | Summary |
|---|---|---|
| 1.2.44 / 0.2.44 | 2026-07-27 | BLE bridge targets the configured VESC id |
| 1.2.43 / 0.2.43 | 2026-07-27 | Display CAN ID in settings |
| 1.2.42 / 0.2.42 | 2026-07-21 | PAS merged to main; CAN-quiet PAS; VESC Tool alongside the app |
| 1.2.41 / 0.2.41 | 2026-07-04 | Deferred battery NVS, trickled trip log — no flash stalls while riding |
| 1.2.40 / 0.2.40 | 2026-07-06 | Hold-to-repeat on the +/− step buttons |
| 1.2.39 / 0.2.39 | 2026-07-05 | 180° flip fixed at render level (reboot to apply) |
| 1.2.38 / 0.2.38 | 2026-07-05 | 180° screen flip option; on-device pedal assist (2026-06-30) |
| 1.2.37 / 0.2.37 | 2026-06-29 | Companion BLE moved into the foreground-service isolate; reconnect hardening |
| 1.2.36 / 0.2.36 | 2026-06-23 | VESC config throttle-curve range −100..100% |

## v1.2.35 / app 0.2.35 — 2026-06-22

LISP quick-action panel with cruise control and profiles, LVGL partial-render
performance work, battery charge/swap detection by voltage.

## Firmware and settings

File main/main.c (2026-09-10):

#include <stdio.h>

#include "bsp/esp-bsp.h"
#include "esp_app_desc.h"
#include "esp_heap_caps.h"
#include "esp_mac.h"
#include "esp_lv_adapter_input.h"
#include "esp_log.h"
#include "esp_netif.h"
#include "esp_rom_sys.h"
#include "esp_system.h"
#include "esp_task_wdt.h"
#include "freertos/FreeRTOS.h"
#include "freertos/task.h"
#include "lvgl.h"
#include "nvs_flash.h"

/* Constructor that runs LATE in do_global_ctors() (priority 65535 = lowest
 * among priority-tagged, but still before untagged constructors).
 * Prints free MALLOC_CAP_INTERNAL+8BIT heap to bracket who consumed it. */
__attribute__((constructor(65535)))
static void heap_probe_post_priority_ctors(void)
{
    size_t internal8 = heap_caps_get_free_size(MALLOC_CAP_INTERNAL | MALLOC_CAP_8BIT);
    size_t largest = heap_caps_get_largest_free_block(MALLOC_CAP_INTERNAL | MALLOC_CAP_8BIT);
    esp_rom_printf("HEAP_PROBE A (post-priority-ctors) free=%u largest=%u\n",
                   (unsigned)internal8, (unsigned)largest);
}

/* port_start_app_hook is a weak symbol declared in
 * components/freertos/app_startup.c, called from esp_startup_start_app()
 * AFTER xTaskCreatePinnedToCore(main_task) but BEFORE vTaskStartScheduler.
 * That's the last point where we can measure heap before IDLE allocs. */
void port_start_app_hook(void)
{
    size_t internal8 = heap_caps_get_free_size(MALLOC_CAP_INTERNAL | MALLOC_CAP_8BIT);
    size_t largest = heap_caps_get_largest_free_block(MALLOC_CAP_INTERNAL | MALLOC_CAP_8BIT);
    esp_rom_printf("HEAP_PROBE B (pre-scheduler) free=%u largest=%u\n",
                   (unsigned)internal8, (unsigned)largest);
}

#include "sdkconfig.h"

#if CONFIG_IDF_TARGET_ESP32P4
#include "aa_overclock.h"
#include "vbat_routing.h"
#endif
#if CONFIG_AA_ENABLE
#include "aa_link_status.h"
#include "bt_agent_ota.h"
#include "bt_link.h"
#include "c6_ota.h"
#include "display_video.h"
#include "h264_pipe.h"
#include "idle_screen.h"
#include "tcp_server.h"
#endif
#include "ble_host.h"
#include "ble_nus.h"
#include "notif_bridge.h"
#include "notif_toast.h"
#include "pas.h"
#include "speed_sensor.h"
#include "music_info_view.h"
#include "gui_guider.h"
#include "dashboard_theme.h"
#include "board.h"
#include "config.h"
#include "dev_settings.h"
#include "display_init.h"
#include "splash_screen.h"
#include "charge_prompt.h"
#include "log_capture.h"
#include "mdns_advertise.h"
#include "ota_http.h"
#include "files_http.h"
#include "lisp_http.h"
#include "ota_screen.h"
#include "touch_input.h"
#include "ui_mode.h"
#include "debug_uart_bridge.h"
#include "vesc_can/comm_can.h"
#include "vesc_battery_calc.h"
#include "vesc_can/vesc_lisp_poll.h"
#include "vesc_can/vesc_lisp_console.h"
#include "vesc_can/vesc_rt_data.h"
#include "vesc_can/vesc_io_data.h"
#include "vesc_can/vesc_lisp_code.h"
#include "vesc_can/vesc_lisp_panel.h"
#include "vesc_config/vesc_config.h"
#include "vesc_config/vesc_config_transport.h"
#include "vesc_sim.h"
#include "vesc_trip_persist.h"
#include "trip_log.h"
#include "vesc_ui_updater.h"
#include "wifi_manager.h"

static const char *TAG = "main";

/* Force ld to pull main/files_screen.c.o out of libmain.a so its strong
 * files_screen_show() overrides the weak printf stub in
 * components/vesc_ui/custom.c (kept so vesc_ui links standalone and the
 * desktop simulator still builds). libvesc_ui.a comes earlier on the link
 * line, so its weak definition would otherwise satisfy custom.c's call and
 * files_screen.c.o would never be pulled in. files_screen.c exports a unique
 * non-weak anchor symbol; referencing it by address here makes ld follow the
 * strong undefined ref into libmain.a, dragging the strong files_screen_show
 * along to win the weak-vs-strong tie-break. */
extern const int files_screen_link_anchor;
__attribute__((used))
static const int *const force_link_main_strongs[] = {
    &files_screen_link_anchor,
};

/* Defined in Super_VESC_Display/custom/lisp_panel.c (vesc_ui component). Opens
 * the LISP quick-action panel; safe to call from any task — it marshals onto
 * the LVGL thread and no-ops unless the dashboard is the live screen. Declared
 * here to avoid pulling the heavy gui_guider/custom.h into the firmware side. */
extern void lisp_panel_open_async(void);

/* ---- Custom LVGL touch indev fed by touch_input.c ----
 *
 * BSP auto-installs its own LVGL touch indev that reads GT911 directly. We
 * unregister it and create our own pointer-typed indev that pulls from
 * touch_input's shared state, so:
 *   - touch_input is the single GT911 reader (no I2C race),
 *   - in TOUCH_MODE_AA the indev sees pressed=false (LVGL stops getting
 *     events even though polling continues),
 *   - in TOUCH_MODE_LVGL touches flow into the dashboard normally.
 *
 * LVGL 8.3 indev API: lv_indev_drv_init + lv_indev_drv_register
 * (lv_indev_create / lv_indev_set_* arrived in LVGL 9). */
static lv_indev_drv_t s_lvgl_touch_drv;

static void lvgl_touch_read_cb(lv_indev_drv_t *drv, lv_indev_data_t *data)
{
    (void)drv;
    bool pressed = false;
    uint16_t x = 0, y = 0;
    touch_input_lvgl_read(&x, &y, &pressed);
    data->state   = pressed ? LV_INDEV_STATE_PRESSED : LV_INDEV_STATE_RELEASED;
    data->point.x = x;
    data->point.y = y;
}

static void install_lvgl_touch_indev(void)
{
    /* Drop BSP's auto-installed touch indev (it would race our reader on
     * the same GT911 over I2C). */
    lv_indev_t *bsp_indev = bsp_display_get_input_dev();
    if (bsp_indev) {
        if (esp_lv_adapter_unregister_touch(bsp_indev) == ESP_OK) {
            ESP_LOGI(TAG, "BSP touch indev unregistered");
        } else {
            ESP_LOGW(TAG, "BSP touch indev unregister failed");
        }
    }

    /* lv_indev_drv_register touches LVGL globals — hold the BSP lock. */
    if (bsp_display_lock(1000) != ESP_OK) {
        ESP_LOGW(TAG, "lvgl indev: bsp_display_lock failed — skipping");
        return;
    }
    lv_indev_drv_init(&s_lvgl_touch_drv);
    s_lvgl_touch_drv.type    = LV_INDEV_TYPE_POINTER;
    s_lvgl_touch_drv.read_cb = lvgl_touch_read_cb;
    lv_indev_t *indev = lv_indev_drv_register(&s_lvgl_touch_drv);
    bsp_display_unlock();
    if (indev) {
        ESP_LOGI(TAG, "custom LVGL touch indev registered");
    } else {
        ESP_LOGW(TAG, "custom LVGL touch indev registration failed");
    }
}

/* Re-assembled VESC packets land here. Forwards to the RT-data parser,
 * (if enabled) the LISP poll parser, and the BLE NUS bridge so VESC Tool
 * over BLE sees CAN responses. All three filter / gate on their own state
 * (RT/LISP on the leading COMM_PACKET_ID byte, NUS on connection state)
 * so the fan-out is unconditional. */
static void vesc_packet_dispatch(const uint8_t *data, unsigned int len)
{
    vesc_rt_data_process_response(data, len);
    /* COMM_LISP_GET_STATS replies. Unconditional: the periodic poll is off by
     * default, but the web editor asks for stats one request at a time and
     * still needs the answer parsed. Gates on data[0] like everything here. */
    vesc_lisp_poll_process_response(data, len);
    /* Script output — COMM_LISP_PRINT / COMM_PRINT — into the console ring
     * the web editor polls. Unsolicited, arrives whenever a script prints. */
    vesc_lisp_console_process_response(data, len);
    /* ADC/PPM decoded inputs for the realtime viewer (gated active). */
    vesc_io_data_process_response(data, len);
    /* LISP code upload/read acks (gated on an in-flight operation). */
    vesc_lisp_code_process_response(data, len);
    /* Config GET/SET/FW_VERSION replies (COMM ids 0, 13-18). Gates on data[0]
     * and ignores packets it doesn't own. */
    vesc_config_transport_process_response(data, len);
    /* LISP quick-action panel UI_DESC/STATE replies (COMM_CUSTOM_APP_DATA +
     * 'VP' magic). Gates internally; ignores everything else. */
    vesc_lisp_panel_process_response(data, len);
    ble_nus_forward_response(data, (uint16_t)len);
}

static void init_nvs(void)
{
    esp_err_t err = nvs_flash_init();
    if (err == ESP_ERR_NVS_NO_FREE_PAGES || err == ESP_ERR_NVS_NEW_VERSION_FOUND) {
        ESP_ERROR_CHECK(nvs_flash_erase());
        err = nvs_flash_init();
    }
    ESP_ERROR_CHECK(err);
}

/* settings_set_can_speed → here. Re-arms the TWAI driver with the new
 * baud rate, keeping the current controller_id from settings. */
static void on_can_speed_changed(int new_kbps)
{
    if (comm_can_reinit(settings_get_controller_id(), new_kbps) != ESP_OK) {
        ESP_LOGW(TAG, "comm_can_reinit(%d kbps) failed", new_kbps);
    }
}

/* settings_set_screen_brightness → here. bsp_display_brightness_set is
 * a thin LEDC duty wrapper, safe to call from the UI task. */
static void on_brightness_changed(uint8_t pct)
{
    bsp_display_brightness_set(pct);
}

/* dashboard_theme switch hook → re-home the phone-side music tile onto the
 * active theme's widget (or tear it down when the theme has none). Fires on the
 * first build and on every live theme switch, always on the LVGL thread with
 * the BSP lock already held by the caller. */
static void on_dashboard_theme_switched(lv_obj_t *screen, lv_obj_t *music_tile)
{
    (void)screen;
    music_info_view_detach();
    if (music_tile) music_info_view_attach(music_tile);
}

/* settings_set_controller_id → here. Reinit TWAI so STATUS_* frames go
 * out under the new ID. Speed comes back from settings (single source). */
static void on_controller_id_changed(uint8_t new_id)
{
    if (comm_can_reinit(new_id, (int)settings_get_can_speed()) != ESP_OK) {
        ESP_LOGW(TAG, "comm_can_reinit(ctrl=%u) failed", new_id);
    }
}

/* settings_set_target_vesc_id → here. Both pollers store the target ID
 * statically; vesc_*_init is documented as safe to call repeatedly so
 * we just re-init them and the next poll cycle hits the new node. */
static void on_target_id_changed(uint8_t new_id)
{
    vesc_rt_data_init(new_id, CONFIG_VESC_CAN_RT_INTERVAL_MS);
    vesc_lisp_poll_init(new_id, CONFIG_VESC_CAN_LISP_INTERVAL_MS);
    vesc_io_data_init(new_id, 150);
    vesc_lisp_code_set_target(new_id);
    vesc_lisp_panel_set_target(new_id);
    ESP_LOGI(TAG, "VESC target ID → %u", new_id);
}

#if CONFIG_AA_ENABLE
/* settings_set_aa_autoconnect → here. Forwards to the BT agent so it can
 * arm or disarm its auto-reconnect-on-boot loop without a P4 restart. The
 * agent persists the value to its own NVS, so this call is also fine if
 * bt_link_init hasn't completed yet — the UART write is a no-op when the
 * driver isn't installed, and the value re-syncs from the explicit send
 * we issue at boot below. */
static void on_aa_autoconnect_changed(bool on)
{
    bt_link_set_auto_reconnect(on);
}
#endif /* CONFIG_AA_ENABLE */

void app_main(void)
{
    /* Install the PSRAM-backed log ring buffer before anything else
     * logs, so the Logs screen in Settings can show the full boot
     * sequence (PMU register dumps, NVS contents, BLE init, …). */
    log_capture_init();

#if CONFIG_AA_ENABLE
    ESP_LOGI(TAG, "%s boot (Android Auto, aa_submode=%d)",
             BOARD_MODEL_NAME, CONNECTION_MODE);
#else
    ESP_LOGI(TAG, "%s boot (VESC dashboard)", BOARD_MODEL_NAME);
#endif

    /* Why did we (re)start? A mid-ride restart is invisible on the dashboard
     * but resets every in-RAM total, so the Logs screen has to be able to
     * answer it after the fact: POWERON is the normal case, TASK_WDT / INT_WDT
     * / PANIC point at a firmware hang, BROWNOUT at the supply. Logged at WARN
     * for anything other than a clean power-on so it stands out in the ring. */
    {
        esp_reset_reason_t rr = esp_reset_reason();
        const char *name;
        switch (rr) {
        case ESP_RST_POWERON:  name = "POWERON";  break;
        case ESP_RST_SW:       name = "SW";       break;
        case ESP_RST_PANIC:    name = "PANIC";    break;
        case ESP_RST_INT_WDT:  name = "INT_WDT";  break;
        case ESP_RST_TASK_WDT: name = "TASK_WDT"; break;
        case ESP_RST_WDT:      name = "WDT";      break;
        case ESP_RST_BROWNOUT: name = "BROWNOUT"; break;
        case ESP_RST_EXT:      name = "EXT";      break;
        case ESP_RST_DEEPSLEEP:name = "DEEPSLEEP";break;
        default:               name = "OTHER";    break;
        }
        if (rr == ESP_RST_POWERON || rr == ESP_RST_SW) {
            ESP_LOGI(TAG, "reset reason: %s (%d)", name, (int)rr);
        } else {
            ESP_LOGW(TAG, "reset reason: %s (%d) — previous run did not exit cleanly",
                     name, (int)rr);
        }
    }

    /* Publish our own (P4) firmware version to dev_settings so the Settings
     * screen can render it. BT + C6 entries get filled in further below as
     * those subsystems come up. */
    {
        const esp_app_desc_t *desc = esp_app_get_description();
        if (desc) fw_info_set_p4(desc->version);
    }
    ESP_LOGI(TAG, "HEAP_PROBE: app_main INTERNAL+8BIT free=%u largest=%u",
             (unsigned)heap_caps_get_free_size(MALLOC_CAP_INTERNAL | MALLOC_CAP_8BIT),
             (unsigned)heap_caps_get_largest_free_block(MALLOC_CAP_INTERNAL | MALLOC_CAP_8BIT));

#if ENABLE_WALL_CLOCK
    /* Arm the PMU so the LP domain runs in AUTO mode (falls through to
     * VBAT/CR2032 when main power collapses). Required for the wall-
     * clock on the dashboard to survive USB-unplug — without this poke,
     * a POR wipes the LP_TIMER and the boot_time epoch in LP_STORE2/3.
     * Has to run before anything else that touches PMU state. */
    vbat_routing_enable();
#endif

    init_nvs();
    /* Settings cache is now ready for both the UI (settings_ui_init pulls
     * via settings_wrapper_init → settings_init) and our callback wiring
     * below. settings_init is idempotent. */
    settings_init();

    /* Smart battery calc needs NVS open before its first percentage call.
     * settings_init's nvs_flash_init has already run; battery_calc keeps its
     * own namespace ("battery_calc") for the remaining-Ah counter. */
    battery_calc_init();
    /* trip_persist tracks trip / Ah / uptime across VESC reboots — same NVS
     * pattern as battery_calc, separate namespace. The dashboard reset icon
     * eventually flows here via battery_calc_reset_trip_and_ah(). */
    trip_persist_init();
    /* Per-trip history on the raw "triplog" partition. MUST stay before
     * display_init(): it erases the dirty part of its sector runway
     * synchronously here, while the panel is still dark — every flash erase
     * freezes the screen otherwise. */
    trip_log_init();

#if CONFIG_IDF_TARGET_ESP32P4
    /* Bump CPU to 400 MHz before any peripheral / WiFi init so APB ratio
     * stays consistent. No-op unless CONFIG_AA_OVERCLOCK_400 is set. */
    aa_overclock_400mhz_apply();
#endif

    if (display_init() != ESP_OK) {
        ESP_LOGW(TAG, "display init failed — UI disabled");
    }
    /* display_init lights the backlight at 100% — apply the saved brightness
     * once the panel is up so user preference takes hold before any UI
     * draws. Brightness callback persists future changes from the slider. */
    bsp_display_brightness_set(settings_get_screen_brightness());
    settings_register_brightness_cb(on_brightness_changed);

    /* Boot splash GIF (if /vescfs/splash.gif exists). Top-layer overlay that
     * covers the ~5 s dashboard build below; hidden once the dashboard is up
     * (splash_screen_hide after ui_mode_init), with a safety auto-hide. */
    splash_screen_show();

    /* idle first, ota second so the OTA overlay sits on top in z-order
     * (children of lv_scr_act() are stacked in creation order). The idle
     * screen is the AA one ("waiting for phone" + Connect); the dashboard-only
     * board never shows it. */
#if CONFIG_AA_ENABLE
    idle_screen_init();
#endif
    ota_screen_init();

    /* Replace BSP's auto-installed LVGL touch indev with our own that reads
     * from touch_input's shared state. Single GT911 reader for both AA and
     * VESC modes — must run before ui_mode_init so the dashboard sees touch
     * from frame 1. */
    install_lvgl_touch_indev();

    /* Register the music-tile re-home hook BEFORE the dashboard is built, so
     * the very first theme build (inside ui_mode_init) attaches the music tile
     * via the same path a live theme switch uses. */
    dashboard_theme_set_switch_cb(on_dashboard_theme_switched);

    /* Build the VESC dashboard offscreen and arm the 3-finger gesture
     * (works in both AA and VESC modes, even before phone connects).
     *
     * super_vesc_ui_init() walks ~1700 lines of GUI Guider widget creation
     * (~750 lv_obj_set_style_* calls) under the BSP lock on prio-1 main task
     * → IDLE0 starves for ~5 s and CONFIG_ESP_TASK_WDT_TIMEOUT_S=5 fires.
     * Detach IDLE0 from TWDT just for this one-shot init. */
    TaskHandle_t idle0 = xTaskGetIdleTaskHandleForCore(0);
    bool wdt_paused = (idle0 && esp_task_wdt_delete(idle0) == ESP_OK);
    esp_err_t ui_err = ui_mode_init();
    if (wdt_paused) {
        esp_task_wdt_add(idle0);
    }

    /* Dashboard (or idle, on failure) is now the live screen underneath —
     * drop the boot splash overlay. No-op if no splash was shown. */
    splash_screen_hide();
    /* "Battery charged — reset trip?" prompt: arm battery_calc's callback
     * now that LVGL is up, before the CAN poller can deliver the first ESC
     * reading (the check runs once per boot on that reading). */
    charge_prompt_init();
    if (ui_err == ESP_OK) {
#if CONFIG_AA_ENABLE
        /* 3-finger gesture toggles between VESC dashboard and AA projection.
         * Only meaningful once the AA stack is up. The GT911 polling task
         * starts unconditionally so LVGL touch keeps working. */
        touch_input_set_gesture_cb(ui_mode_toggle);
#endif
        /* Left-edge swipe opens the LISP quick-action panel. The handler
         * marshals to the LVGL task and no-ops unless the dashboard is the
         * live screen, so registering it unconditionally is safe. */
        touch_input_set_edge_swipe_cb(lisp_panel_open_async);
        touch_input_start(NULL, NULL);

        /* The phone-side music tile is now attached by the dashboard-theme
         * switch hook (on_dashboard_theme_switched), fired during the first
         * theme build inside ui_mode_init — no manual attach needed here, and
         * it re-homes correctly across live theme switches. */
    }

    /* Debug bridge over UART0 console: host-driven screenshot + touch
     * injection for UI test automation. No-op stub unless built with
     * CONFIG_DEBUG_UART_BRIDGE. Needs the display + indev up (done above). */
#if CONFIG_DEBUG_UART_BRIDGE
    debug_uart_bridge_init();
#endif

    /* VESC CAN bring-up. Independent from the AA pipeline — runs the
     * second the dashboard is alive so RT data starts streaming even
     * before WiFi is up. The decode-side handler routes reassembled
     * VESC packets to vesc_rt_data (and vesc_lisp_poll if enabled). */
    int     can_kbps = (int)settings_get_can_speed();
    uint8_t ctrl_id  = settings_get_controller_id();
    uint8_t tgt_id   = settings_get_target_vesc_id();
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

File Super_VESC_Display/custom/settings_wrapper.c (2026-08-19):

/*
	Copyright 2025 Super VESC Display
	
	Settings wrapper for LVGL GUI (works in simulator and on device)
*/

#include "settings_wrapper.h"
#include "lv_conf.h"
#include <stdio.h>
#include <time.h>

// Determine if we're running in simulator using LVGL's flag
#ifndef LV_REALDEVICE
    #define SIMULATOR_MODE 1
#else
    #define SIMULATOR_MODE 0
    // On device - include real settings
    #include "dev_settings.h"
    #include "vesc_head2.h"
    #include "esp_system.h"
    #include "freertos/FreeRTOS.h"
    #include "freertos/task.h"
#endif

// Simulator-mode storage
#if SIMULATOR_MODE
static struct {
    uint8_t target_vesc_id;
    uint8_t can_speed_index;
    uint8_t brightness;
    uint8_t controller_id;
    float battery_capacity;
    uint8_t battery_calc_mode;
    bool show_fps;
    uint16_t wheel_diameter_mm;
    uint8_t motor_poles;
    float power_max_kw;
    uint32_t clock_offset_secs;
    bool aa_autoconnect;
    bool use_imperial;
    bool use_fahrenheit;
    bool second_head_enabled;
    bool brightness_gesture_enabled;
    uint8_t second_head_id;
    uint8_t dashboard_theme;
    uint8_t splash_loops;
    bool display_flip;
} sim_settings = {
    .target_vesc_id = 10,
    .can_speed_index = 3,  // 1000 kbps
    .brightness = 80,
    .controller_id = 255,
    .battery_capacity = 15.0f,
    .battery_calc_mode = 0,  // Direct
    .show_fps = true,
    .wheel_diameter_mm = 200,  // 200mm default
    .motor_poles = 7,  // Standard for VESC motors
    .power_max_kw = 4.5f,
    .clock_offset_secs = 0,
    .aa_autoconnect = true,
    .use_imperial = false,
    .use_fahrenheit = false,
    .second_head_enabled = false,
    .brightness_gesture_enabled = true,
    .second_head_id = 11,
    .dashboard_theme = 0,
    .splash_loops = 1,
    .display_flip = false,
};
#endif

/* km → miles. Same factor converts km/h → mph. */
#define MILES_PER_KM 0.621371f

void settings_wrapper_init(void) {
#if !SIMULATOR_MODE
    settings_init();
#endif
}

uint8_t settings_wrapper_get_target_vesc_id(void) {
#if SIMULATOR_MODE
    return sim_settings.target_vesc_id;
#else
    return settings_get_target_vesc_id();
#endif
}

uint8_t settings_wrapper_get_can_speed_index(void) {
#if SIMULATOR_MODE
    return sim_settings.can_speed_index;
#else
    // Convert kbps to index
    can_speed_t speed = settings_get_can_speed();
    switch ((int)speed) {
        case 125: return 0;
        case 250: return 1;
        case 500: return 2;
        case 1000: return 3;
        default: return 1; // Default to 250
    }
#endif
}

uint8_t settings_wrapper_get_brightness(void) {
#if SIMULATOR_MODE
    return sim_settings.brightness;
#else
    return settings_get_screen_brightness();
#endif
}

uint8_t settings_wrapper_get_controller_id(void) {
#if SIMULATOR_MODE
    return sim_settings.controller_id;
#else
    return settings_get_controller_id();
#endif
}

float settings_wrapper_get_battery_capacity(void) {
#if SIMULATOR_MODE
    return sim_settings.battery_capacity;
#else
    return settings_get_battery_capacity();
#endif
}

uint8_t settings_wrapper_get_battery_calc_mode(void) {
#if SIMULATOR_MODE
    return sim_settings.battery_calc_mode;
#else
    return (uint8_t)settings_get_battery_calc_mode();
#endif
}

bool settings_wrapper_get_show_fps(void) {
#if SIMULATOR_MODE
    return sim_settings.show_fps;
#else
    return settings_get_show_fps();
#endif
}

uint16_t settings_wrapper_get_wheel_diameter_mm(void) {
#if SIMULATOR_MODE
    return sim_settings.wheel_diameter_mm;
#else
    return settings_get_wheel_diameter_mm();
#endif
}

uint8_t settings_wrapper_get_motor_poles(void) {
#if SIMULATOR_MODE
    return sim_settings.motor_poles;
#else
    return settings_get_motor_poles();
#endif
}

void settings_wrapper_set_target_vesc_id(uint8_t id) {
#if SIMULATOR_MODE
    sim_settings.target_vesc_id = id;
#else
    settings_set_target_vesc_id(id);
#endif
}

void settings_wrapper_set_can_speed_index(uint8_t index) {
#if SIMULATOR_MODE
    sim_settings.can_speed_index = index;
#else
    // Convert index to speed
    can_speed_t speed;
    switch (index) {
        case 0: speed = CAN_SPEED_125_KBPS; break;
        case 1: speed = CAN_SPEED_250_KBPS; break;
        case 2: speed = CAN_SPEED_500_KBPS; break;
        case 3: speed = CAN_SPEED_1000_KBPS; break;
        default: speed = CAN_SPEED_250_KBPS; break;
    }
    settings_set_can_speed(speed);
#endif
}

void settings_wrapper_set_brightness(uint8_t brightness) {
#if SIMULATOR_MODE
    sim_settings.brightness = brightness;
#else
    settings_set_screen_brightness(brightness);
#endif
}

void settings_wrapper_set_controller_id(uint8_t id) {
#if SIMULATOR_MODE
    sim_settings.controller_id = id;
#else
    settings_set_controller_id(id);
#endif
}

void settings_wrapper_set_battery_capacity(float capacity) {
#if SIMULATOR_MODE
    sim_settings.battery_capacity = capacity;
#else
    settings_set_battery_capacity(capacity);
#endif
}
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

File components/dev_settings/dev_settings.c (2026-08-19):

#include "dev_settings.h"

#include <stdio.h>
#include <string.h>
#include <sys/time.h>
#include <time.h>

#include "esp_log.h"
#include "nvs.h"
#include "nvs_flash.h"
#include "sdkconfig.h"
#include "vesc_battery_calc.h"

static const char *TAG = "dev_settings";
#define NS "vesc_cfg"

/* RAM cache — populated once on settings_init(). Setters update both NVS
 * and cache, getters return cache. The cache is the source of truth at
 * runtime; NVS is only re-read on cold boot. */
static struct {
    bool                 loaded;
    uint8_t              target_vesc_id;
    can_speed_t          can_speed;
    uint8_t              brightness;
    uint8_t              controller_id;
    float                battery_capacity;
    battery_calc_mode_t  battery_calc_mode;
    bool                 show_fps;
    uint16_t             wheel_diameter_mm;
    uint8_t              motor_poles;
    float                power_max_kw;
    bool                 vesc_emulator;
    bool                 aa_autoconnect;
    bool                 use_imperial;
    bool                 use_fahrenheit;
    bool                 second_head_enabled;
    bool                 brightness_gesture_enabled;
    uint8_t              second_head_id;
    uint8_t              dashboard_theme;
    uint8_t              splash_loops;     /* boot-splash repeats; 0 = off */
    bool                 display_flip;     /* 180° flip for upside-down mount */
} s_cache;

static settings_can_speed_cb_t     s_can_speed_cb;
static settings_brightness_cb_t    s_brightness_cb;
static settings_target_id_cb_t     s_target_id_cb;
static settings_controller_id_cb_t s_controller_id_cb;
static settings_aa_autoconnect_cb_t s_aa_autoconnect_cb;

/* Validate a kbps value (read from NVS / passed by callers). Bad values
 * fall back to the Kconfig default. The UI dropdown can only produce one
 * of these four, but NVS contents could be anything if the partition was
 * tampered with or migrated from an older firmware. */
static can_speed_t sanitize_can_speed(uint16_t v) {
    switch (v) {
        case 125:  return CAN_SPEED_125_KBPS;
        case 250:  return CAN_SPEED_250_KBPS;
        case 500:  return CAN_SPEED_500_KBPS;
        case 1000: return CAN_SPEED_1000_KBPS;
        default:   return (can_speed_t)CONFIG_VESC_CAN_SPEED_KBPS;
    }
}

static void load_from_nvs(void) {
    nvs_handle_t h;
    esp_err_t err = nvs_open(NS, NVS_READONLY, &h);
    if (err == ESP_ERR_NVS_NOT_FOUND) {
        /* Namespace missing on first boot — leave cache at defaults. */
        ESP_LOGI(TAG, "no NVS namespace yet, using defaults");
        return;
    }
    if (err != ESP_OK) {
        ESP_LOGW(TAG, "nvs_open RO failed: %s — using defaults",
                 esp_err_to_name(err));
        return;
    }

    uint8_t  u8;
    uint16_t u16;

    if (nvs_get_u8 (h, "tgt_vesc_id", &u8 ) == ESP_OK) s_cache.target_vesc_id    = u8;
    if (nvs_get_u16(h, "can_kbps",    &u16) == ESP_OK) s_cache.can_speed         = sanitize_can_speed(u16);
    if (nvs_get_u8 (h, "brightness",  &u8 ) == ESP_OK) s_cache.brightness        = u8;
    if (nvs_get_u8 (h, "ctrl_id",     &u8 ) == ESP_OK) s_cache.controller_id     = u8;
    if (nvs_get_u8 (h, "batt_calc",   &u8 ) == ESP_OK) s_cache.battery_calc_mode = (battery_calc_mode_t)u8;
    if (nvs_get_u8 (h, "show_fps",    &u8 ) == ESP_OK) s_cache.show_fps          = (u8 != 0);
    if (nvs_get_u8 (h, "vesc_sim",    &u8 ) == ESP_OK) s_cache.vesc_emulator     = (u8 != 0);
    if (nvs_get_u8 (h, "aa_autocon",  &u8 ) == ESP_OK) s_cache.aa_autoconnect    = (u8 != 0);
    if (nvs_get_u8 (h, "use_imp",     &u8 ) == ESP_OK) s_cache.use_imperial      = (u8 != 0);
    if (nvs_get_u8 (h, "use_fahr",    &u8 ) == ESP_OK) s_cache.use_fahrenheit    = (u8 != 0);
    if (nvs_get_u8 (h, "sh_en",       &u8 ) == ESP_OK) s_cache.second_head_enabled = (u8 != 0);
    if (nvs_get_u8 (h, "br_gest_en",  &u8 ) == ESP_OK) s_cache.brightness_gesture_enabled = (u8 != 0);
    if (nvs_get_u8 (h, "sh_id",       &u8 ) == ESP_OK) s_cache.second_head_id    = u8;
    if (nvs_get_u8 (h, "dash_theme",  &u8 ) == ESP_OK) s_cache.dashboard_theme   = u8;
    if (nvs_get_u8 (h, "splash_loops",&u8 ) == ESP_OK) s_cache.splash_loops      = u8;
    if (nvs_get_u8 (h, "disp_flip",   &u8 ) == ESP_OK) s_cache.display_flip      = (u8 != 0);
    if (nvs_get_u16(h, "wheel_mm",    &u16) == ESP_OK) s_cache.wheel_diameter_mm = u16;
    if (nvs_get_u8 (h, "motor_poles", &u8 ) == ESP_OK) s_cache.motor_poles       = u8;

    /* float via blob — NVS has no native float type. */
    size_t sz = sizeof(float);
    float  fv;
    if (nvs_get_blob(h, "batt_cap", &fv, &sz) == ESP_OK && sz == sizeof(float)) {
        s_cache.battery_capacity = fv;
    }
    sz = sizeof(float);
    if (nvs_get_blob(h, "pwr_max", &fv, &sz) == ESP_OK && sz == sizeof(float)) {
        s_cache.power_max_kw = fv;
    }

    nvs_close(h);
}
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

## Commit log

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2026-04-29 Stage 1 + embedded C6 OTA + Waveshare BSP
    - Mode B head unit skeleton: ESP-Hosted SoftAP/STA via WiFi Remote,
    mDNS _androidauto._tcp on 5277, TCP listener (placeholder for AA).
    Role/SSID/PSK selectable through Kconfig.
    - C6 slave firmware (network_adapter.bin) embedded into the host
    binary via EMBED_FILES; on boot, c6_ota.c compares slave fw version
    with host and pushes the embedded blob over SDIO if they differ,
    then activates and restarts. No extra partition or flash step needed.
    - LVGL progress screen (CONFIG_C6_OTA_DISPLAY_PROGRESS) — currently
    off by default while we're tracking down a DSI hang on the panel.
    - Swapped csvke JC4880P443C BSP for the Waveshare
    ESP32-P4-WIFI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
    [partitions.csv]
2026-05-02 Mode A skeleton: BT Classic agent on D1 Mini + AAP service hardening
    Wireless Mode B (mDNS-only) is dead end on modern Android Auto — phone
    reaches PROJECTION_WINDOW_MANAGER_STARTING and stalls because gearhead
    takes the new "Cakewalk" wireless path which silently blocks DIY HUs
    (same issue OpenAuto Pro hit late 2023). Cakewalk eligibility is decided
    phone-side from app/OS state, not from anything we send, so the Mode B
    flow can't get past it without either a downgraded AA APK or a wired
    USB AA path.
    This commit lands the Mode A scaffolding (external ESP32-WROOM doing BT
    Classic pairing + AA Wireless setup over RFCOMM) plus all the per-channel
    AAP handlers and Service Discovery tweaks we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
    [bt_link.c, bt_link.h, main.c]
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2026-05-02 Stage VID: H.264 → display path, ending at CPU-bypass debug
    Brings up the full video pipeline behind the AAP video channel and
    proves the decoded image is correct. Final piece — handing PPA the
    right rotation/scale to land it on the panel without tiling — is still
    in flight; the CPU YUV bypass currently in display_video.c shows the
    AA UI cleanly, with the picture vertically flipped at the moment.
    Components added / changed
    - main/h264_pipe.[ch] — FreeRTOS byte-stream ring buffer (256 KiB) +
    decoder task running esp_h264_dec_process. AAP video hands payload
    via h264_pipe_push() (drops on overflow rather than stalling the
    AAP recv loop). CONFIG_ESP_H264_DUAL_TASK=y so the decode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
    [main.c]
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2026-05-02 Stage IN: GT911 touch → AA InputEvent + recv reassembly + h264 recovery
    touch_input polls the GT911 (already initialised by the BSP) at 50 Hz,
    maps panel-native portrait coords to AA landscape (the CPU YUV→RGB+
    transpose pipeline draws AA(ax,ay) at panel(479-ay,ax), so the inverse
    is ax=panel_y, ay=479-panel_x), and invokes a callback for each
    PRESS/DRAG/RELEASE. aa_service registers a callback that builds an
    InputEventIndication on channel id=1 (msg=0x8001). DRAG events at the
    same position are dropped to keep the channel quiet under static
    fingers.
    Sending touch events from a parallel task surfaced two concurrency
    issues with the existing recv loop:
    1. mbedtls SSL state isn't thread-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
    [esp32_p4_wifi6_touch_lcd_4_3.c]
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2026-05-05 Add Super_VESC_Display GUI Guider project
    Vendored standalone LVGL 8.3 dashboard project (NXP GUI Guider export
    plus simulator). Used as the visual source for the VESC head-unit mode
    the AA project will switch to via 3-finger touch. Kept self-contained
    so the desktop simulator (lvgl-simulator/) keeps building independently.
    One source-level fix vs upstream backup: int cruise_active = 0 moved
    out of the #ifdef LV_REALDEVICE block in custom/custom.c — without
    LV_REALDEVICE (simulator path) the symbol was undeclared at line 219.
    [board.h, custom.c, main.c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]
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2026-05-06 main: split ota_screen into display_init / idle_screen / ota_screen overlay
    - display_init.c: LVGL panel bring-up extracted from ota_screen_init
    - idle_screen.c: "Android Auto / Initialising Wi-Fi…" screen, was
    ota_screen_show_idle
    - ota_screen.c: now just the OTA progress overlay; ota_screen_hide
    drops it after C6 update completes
    - display_video: don't replace panel event_callbacks; the LVGL adapter
    registers on_refresh_done/on_color_trans_done at init and
    esp_lcd_dpi_panel_register_event_callbacks REPLACES, not appends —
    taking those over leaves the adapter's flush blocked on completion
    - h264_pipe: pin decoder task to core 1 (same as openh264 dual-task
    helper) so LVGL on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
    [main.c]
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2026-05-07 threading: pin AA+decoder to core 1, UI to core 0; throttle AA to 5fps in VESC mode
    In VESC mode the H.264 decoder used to run at full 30 fps and discard the
    output, wasting ~90% of one core. Throttle ack rate to 5 fps in h264_pipe so
    gearhead's max_unacked window slows the phone — decoder stays current for a
    clean switch back to AA but burns ~6× less CPU.
    Pin aa_tcp + LwIP tiT to core 1 alongside h264_dec so the recv → decode chain
    stays on one core; pin LVGL/touch/CAN/BLE bridge bits to core 0. Drop dual-task
    mode in the H.264 decoder — both worker threads were stuck on core 1 anyway,
    so the prio-17 helper just preempted the recv-loop without giving real SMP.
    Backpressure is handle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
    [bt_link.c]
2026-05-07 custom: fix settings buttons disappearing after AA/VESC toggle
    settings_ui_init's NULL-pointer guard treated stale pointers as
    "already initialized". gui_guider's ui_load_scr_animation never
    clears settings_del after calling setup_scr, so re-entering Settings
    without going through "Back to dashboard" recreated ui->settings —
    orphaning our buttons while the guard suppressed re-creation. Switch
    the guard to a parent check so orphaned state falls through to the
    build path.
    Also: guider regen (FADE_ON → MOVE_BOTTOM/TOP screen anims), enable
    LV_FONT_FMT_TXT_LARGE for Antonio_Regular_220 (12-bit bitmap_index
    overflow), drop unused montserratMedium_9 font.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
    [custom.c]
2026-05-07 fw blobs: gzip-pack + survive long UART OTA writes
    Compress the embedded slave/agent firmware blobs (~933 KiB host flash
    saved) and turn the BT-agent OTA into a setup that actually finishes on
    this board. The single 1 MiB write over UART against a busy P4 had been
    failing reproducibly — at 0x2000 with raw ROM, around the 80% mark with
    stub — because various bits of the host kept stealing UART RX cycles
    while the agent's checksum byte was on the wire.
    Compression:
    - components/bt_agent_fw and components/c6_ota_partition embed the .gz
    variant (~57% of raw) and decompress lazily into PSRAM via miniz on
    first access. Adds espressif__zlib + esp_psram to PRIV_REQUIRES; one
    z_stream + IS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
    [bt_agent_ota.c, bt_link.c, bt_link.h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]
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2026-05-13 avrcp+ota: wifi http OTA, fix metadata, unicode song titles
    * WiFi HTTP OTA server on the SoftAP (port 80): POST app binary
    to /ota and the device flashes the inactive slot, sets boot,
    reboots. New partition layout with ota_0/ota_1, otadata.
    scripts/ota_push.sh helper for curl-from-laptop. The AVRCP
    path now brings up the SoftAP too so OTA works without AA.
    * AVRCP CT/A2DP init order was reversed — Bluedroid checks at
    esp_a2d_sink_init time whether AVRC is registered and, if
    not, logs "AVRC not Init, not using it" and silently skips
    AVRC for that A2DP link. Phones paired but META never came.
    Swap to AVRC CT first, then A2DP sink.
    * Custom unicode subset font (Latin + Lati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
    [partitions.csv]
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2026-05-15 settings: compact single-row layout, drop spinbox for plain labels
    The spinbox widget never made sense — values are always driven by the
    +/- buttons, so the editor-style border/cursor were just visual noise.
    Replace with a centred coloured label and a tiny num_field_t helper
    (value/min/max/step/decimals + on_change) that consolidates the three
    numeric settings.
    Layout now puts heading on the left and controls on the right edge of
    the 800px screen instead of stretching a single spinner across the
    full width. Row height 60 (was 90+); switches/dropdowns aligned with
    the same right-edge column for visual consistency.
    [custom.c]
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2026-05-17 vbat: keep RTC alive across POR via AUTO-mode PMU poke
    Wall-clock time on the dashboard now survives USB unplug, EN-cycle
    RESET, and brownout as long as the CR2032 on H8 is healthy. The trick:
    write VBAT_MODE_AUTO (2) into both LP_ACTIVE and LP_SLEEP slots of
    PMU.lp_sys[*].dig_power, set bod_source_sel=1 (so the LP brownout
    watches VBAT instead of VDDA), and commit via PMU.vbat_cfg.sw_update.
    ESP-IDF's official esp_vbat_init only writes vddbat_mode=1 into
    PMU_MODE_LP_SLEEP and only commits at deep_sleep_start entry, so cold
    POR never went through the LP_SLEEP transition and the LP domain came
    up freshly from VDDA — wiping LP_TIMER and LP_STORE2/3 where the RTC
    boot_time epoch lives. The A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
    [partitions.csv]
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2026-05-18 logs: PSRAM ring buffer + viewer screen in Settings
    Captures everything that goes through ESP_LOGx into a 1 MB ring buffer
    in PSRAM (in addition to the UART console). A "Logs" button on the
    Settings screen opens a viewer that live-tails the last 16 KB at 500 ms,
    colorized by level via LVGL recolor tags (I/W/E/D/V). Fixed label width
    + LONG_CLIP keeps set_text fast — re-layout doesn't have to rescan the
    whole text for size.
    Also: replace the "CC" speed-widget text in the AA overlay with the
    cruise-control glyph (alpha-mask tint + 1px halo, same blend as text);
    silence per-touch and per-refresh debug logs so the ring buffer stays
    useful.
    [custom.c, main.c]
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2026-05-30 ble-bridge: music tile, ru/pl fonts, 72px app icons, BT agent 0.6.2
    P4 side:
    - music_info_view.c/h: 350×135 album-art tile in the dashboard with
    cover-fit art, 50% black readability overlay, scrolling title+artist
    (both aabridge_font_32). Parent tileview hidden until first track
    lands so the dashboard background shows through.
    - notif_toast.c: shrink icon slot to 72×72 to match the phone-side PNG —
    lv_img tiles smaller-than-box sources rather than scaling, which
    surfaced as the "one tile + three half-tiles" bug. Card flex centers
    children vertically. Sender font 24, body font 24, PNG icon path via
    LV_IMG_CF_RAW_ALPHA, polled inbox_seq for monotonic delivery.
    - notif_bridge: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
    [board.h, custom.c, main.c]
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2026-06-04 feat(trip-log): raw circular trip log on dedicated triplog partition
    Replace the LittleFS per-trip-folder logger with a raw circular log on a
    dedicated 12.1 MB "triplog" flash partition (esp_partition, no filesystem).
    Trips are no longer stored in LittleFS at all — LittleFS (storage, now 4 MB)
    keeps only VESC config backups.
    Why: writing a sample every 10 s through LittleFS triggers unpredictable
    metadata-compaction / block-allocation erases; a flash erase disables the
    cache for all cores and stalls the DSI/LVGL render path (the screen blinks).
    The raw log lets us control exactly when erasing happens.
    - 64-byte fixed records (magic/type/trip_id/seq/t_s/distance/ah/wh/uptime/
    speed/curr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
    [partitions.csv]
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2026-06-05 fix(jc4880): 5 MB OTA slots, bigger triplog
    Shrink the JC4880P443C OTA slots from 6 MB to 5 MB each (app image is
    ~3.8 MB → ~1.2 MB / 24% headroom) and hand the freed 2 MB to the triplog
    partition (2.875 MB → 4.875 MB). storage stays at 1 MB; triplog still
    ends exactly at the 16 MB boundary. trip_log reads the partition size
    dynamically (esp_partition), so no code change is needed.
    Note: the partition table can't change over OTA — devices need a full
    reflash (which wipes existing storage + triplog) to pick up the new
    layout. The committed jc4880 *-merged.bin still carries the old 6 MB
    layout and will be regenerated at the next release cut.
    Docs (README, README.ru, CLAUDE.md) updated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
    [partitions_16mb.csv]
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2026-06-09 feat(files+splash): on-device file browser, BLE file manager, boot splash GIF
    Firmware:
    - on-device file browser (synthetic root over /vescfs + microSD) from Settings
    - ble_files: list/download/upload/delete/rename/mkdir over a new NotifBridge
    CTRL/DATA char pair (...0009/...000a); worker task + PSRAM staging + SHA-256
    - boot splash GIF (S:/vescfs/splash.gif) on the LVGL top layer
    - enable LV_USE_FS_POSIX + LV_USE_GIF; FATFS long filenames (LFN_HEAP + UTF-8)
    Fixes from on-hardware testing:
    - per-message chunk seq (was per-chunk) — multi-chunk listings/downloads were
    silently dropped by the phone's reassembler
    - patient notify_chunk/notify_status — ride out NimBLE TX-buffer (ENOMEM)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
    [custom.c, esp32_p4_wifi6_touch_lcd_4_3.c, main.c]
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2026-06-12 fix(vesc-can): serialize CAN polls on one task; cruise/profile via DASH
    Reply-expecting CAN polls (RT data, LISP stats, IO, quick-action panel)
    all shared the single per-id reassembly buffer; overlapping multi-frame
    replies clobbered it -> PROCESS_RX_BUFFER CRC mismatches that dropped the
    cruise/mode data. They now run on the one rt_task and wait for each reply
    (comm_can_send_buffer_sync) before sending the next - no mutex, no overlap.
    - comm_can: add comm_can_send_buffer_sync (reply-completion semaphore);
    bump can_proc stack 3072->4096
    - vesc_lisp_panel: parse UI_DESC into a static vlp_model_t (it was ~1.2KB
    on the small can_proc stack -> overflow + reboot the moment a panel
    descript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
    [custom.c]
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2026-06-15 perf(lvgl): partial rendering via DOUBLE_DIRECT — fix laggy full-frame UI
    The UI ran in DOUBLE_FULL (full_refresh): every change re-rendered the whole
    384k px screen in software into PSRAM (~51 ms/frame → ~19 fps ceiling), so any
    swipe/scroll/animation lagged. We were stuck on DOUBLE_FULL because of an
    over-broad "partial rendering always freezes on this P4" conclusion — but that
    came from TRIPLE_PARTIAL, which hangs on the DMA2D front→back copy
    (copy_unrendered_area_from_front_to_back, portMAX_DELAY), a bug the PPA patch
    does NOT cover.
    DOUBLE_DIRECT is also a partial mode but uses a different flush
    (flush_direct_rotate → flush_dirty_copy → rotate_copy_region): it rotates only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
    [esp32_p4_wifi6_touch_lcd_4_3.c]
2026-06-16 fix(lvgl): don't draw dashboard widgets off-screen; uncompress cockpit fonts
    Two follow-ups to the DOUBLE_DIRECT partial-render switch (0fcc7d0):
    1. Off-dashboard widget bleed. In full_refresh the whole active screen was
    repainted each frame, so updates aimed at dashboard widgets while another
    screen showed were just wasted. In DIRECT (partial) mode those updates
    invalidate off-screen dashboard regions and the adapter redraws them →
    dashboard values bleed through Settings / Statistics ("values appear and
    disappear"). Gate the three periodic dashboard writers so they no-op unless
    the dashboard is the active screen:
    - vesc_ui_updater.c: lv_scr_act() != dashboard_theme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
    [custom.c]
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2026-06-29 feat(pas): on-device pedal-assist (PAS) — head unit owns it end-to-end
    Cadence sensor + PAS live entirely on the head unit; phone not involved.
    - BLE dual-role: NimBLE central GATT client to a BK6LS cadence sensor
    (main/ble_cadence_client.c) alongside the existing peripheral. sdkconfig
    CENTRAL/OBSERVER/GATT_CLIENT roles enabled (C6 slave unchanged).
    - PAS loop (main/pas.c): signed RPM -> reverse -> target current per the
    NVS-backed settings -> vesc_lisp_panel_set_pas(), forwarded on the CAN
    rt_task with a ~400ms watchdog (sensor drop -> coast).
    - LISP arbiter (lisp/main.lisp): throttle-override via app-disable-output
    (COMM_CUSTOM_APP_DATA opcode 0x05 + pas-control-loop); cruise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
    [custom.c, main.c]
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2026-07-04 fix(stats): no flash stalls on the ride — deferred battery NVS, trickled trip-log runway
    Riders saw the screen (and touch/AA) freeze around the periodic stats save.
    The 10 s trip_log write itself was already async; the stalls came from the
    smart-battery tracker committing to NVS every 30 s ON the LVGL thread (and
    from the AA video task via the overlay), where each page-full GC adds a 4 KB
    erase that stalls both cores' cache (flash suspend unavailable on this chip).
    - battery_calc: all NVS I/O moved to a batt_sav writer task (snapshot queue);
    statics guarded by a recursive mutex (LVGL + AA video callers).
    - battery state now persists inside the 10 s trip record (v3: remaining_ah +
    rese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
    [trip_log.c]
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2026-07-05 feat(display): 180-degree screen flip option for upside-down mounting
    New "Flip screen 180" switch on the Settings screen (NVS "disp_flip",
    default off). The flip is done at the ST7701 panel level (SDIR source-scan
    + MADCTL gate-scan over DSI-DBI), so it costs nothing at render time and
    flips every pixel source at once — LVGL, the AA video bypass path and the
    boot splash. GT911 coords are inverted in touch_input's poll_task before
    the LVGL/AA rotation, so touch, edge swipe and AA input all match; the
    debug-bridge injection stays screen-space and is untouched. Applied from
    NVS before the backlight comes on at boot, hot-applies on toggle via the
    dev_settings callback pattern.
    Co-Authored-By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
    [custom.c, dev_settings.c, dev_settings.h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]
2026-07-05 fix(display): flip 180 at render level — panel-level mirror garbles the panel
    HW test on jc4880 showed esp_lcd_panel_mirror (ST7701 SDIR/SS + MADCTL/ML)
    produces garbage/stripes even when applied right after init: the DPI pixel
    stream's scan order is fixed, so the data has to be flipped, not the panel.
    Replace with a render-level flip, latched at boot in display_init:
    - LVGL adapter rotation 90 -> 270 (start-time only, so the Settings toggle
    now says "reboot to apply" and the row is labelled "(reboot)")
    - AA video + boot splash PPA rotation_angle 270 -> 90
    - AA HUD overlay inverts both panel axes in blend_user_pixel
    - touch keeps the panel-native inversion but reads the boot-latched
    d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
    [custom.c, dev_settings.c, dev_settings.h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]
2026-07-06 feat(settings): hold-to-repeat on the +/- step buttons
    Holding any settings +/- button now autorepeats via LVGL's long-press
    repeat (100 ms), accelerating x5 after ~2 s and x20 after ~5 s so wide
    ranges (battery 10..2000, power 1..1000) stay crossable in seconds.
    Single taps still step exactly once: the buttons listen to SHORT_CLICKED
    + LONG_PRESSED_REPEAT instead of CLICKED, which also fires on the release
    that ends a hold. Clock hour/minute keep a constant repeat rate (no
    accel) — small wrapping ranges want precision, not speed.
    [custom.c]
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2026-08-02 release: fw 1.3.2 + app 0.3.2 (web LISP editor, CAN identity, traction control)
    Firmware
    - Web LISP editor at /lisp on the head unit's own HTTP server (main/lisp_http.c
    + main/web/lisp_editor.html, gzipped at build time and embedded in .rodata,
    ~15 KiB). Highlighting, line numbers, matching/rainbow parens, find/replace,
    linter, the on-device script library, Read/Upload/Run over CAN with progress,
    a live (print ...) console and a REPL line.
    - Transfers are asynchronous — POST returns 202 and the page polls
    /lisp/api/state. httpd serves every connection from one task, so a blocking
    handler would freeze /files and /ota for the whole upload.
    - vesc_lisp_console.{c,h}: ring for COMM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
    [main.c]
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2026-08-03 feat(dashboard): three concept themes, drop amber and the DSEG fonts
    Replaces the amber dashboard with Classic Max, Lamborghini and Supermoto (plus a
    reference screen), generated through the new tools/build_classic_max.py and
    tools/build_concept_dashboards.py.
    Removing amber removes its 14-segment fonts: no screen references DSEG7/DSEG14
    any more, so they are neither compiled from generated/guider_fonts nor re-subset
    into the build. The .ttf files stay in import/font/, and the CMake comment says
    what to re-add to bring them back. Antonio gains a size-100 subset.
    The lvgl-simulator's dashboard_themes_auto.c is generated from gui_guider.h by
    scripts/gen_dashboard_themes.py, so it is now giti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
    [board.h, custom.c]
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2026-08-10 fix(display): render watchdog, gated log erases, dual-head temps
    Work carried over from the freeze / blue-flash hunt on 1.3.6 plus the
    dual-motor dashboard support.
    Freeze + blue flashes:
    - display_init: a render watchdog forces a full-screen invalidate when no
    LVGL refresh happened for 2 s. Root cause of the "dashboard stops
    updating until you tap it" bug is still open; this heals it the same way
    the tap does. DISPLAY_PERF_LOG re-enabled while the hunt is on.
    - trip_log: a sector erase (each one = a full-screen blue DSI-underrun
    flash on this board) now needs a SUSTAINED standstill. A mid-ride CAN
    dropout used to read as "parked" instantly and flashed the screen while
    the bike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
    [custom.c, debug_uart_bridge.c, settings_wrapper.c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]
2026-08-10 fix(trip): stop showing the VESC's raw counters as the trip
    Field report: a 10 km ride displayed TRIP 255.1 km, uptime 06:28:04,
    RANGE 2340.7 km. Those are the controller's own lifetime counters, not
    the trip.
    trip_persist tracks `raw VESC counter + offset`, where the offset is
    (total we resumed) - (raw counter at that moment). That offset is
    NEGATIVE in the normal case: the VESC keeps counting while the display is
    off or restarting, so its counters are far ahead of the trip being
    resumed. All three offsets were clamped at 0 "to be safe", which turned
    the formula into "display the raw counter". Invisible whenever both
    boards power up together (small counters, positive offset) — and
    guaran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
    [main.c]
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2026-09-02 feat(stats): trip statistics opt-in (default off) + runway erases at boot
    Field report: the dashboard freezes for a moment, often. Every flash write
    or erase on this board suspends the cache for both cores and stalls the DSI
    DMA feeding the panel from PSRAM (AUTO_SUSPEND unavailable on the GD25Q256),
    and the trip log was the one subsystem touching flash during a ride: a
    64-byte record every 10 s plus 4 KB sector erases (45-400 ms each) whenever
    the pre-erased runway ahead of the head had to be rebuilt.
    The boot path never cleaned anything - it read one record per sector to
    find the head and erased two sectors ahead; the erases of the stale data
    ran from the writer's idle loop, i.e. at every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
    [custom.c, dev_settings.c, dev_settings.h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]
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2026-09-02 fix(aa): grow the message reassembly buffer; drop the trip-stats switch
    Android Auto dropped mid-session in a 2026-09-02 field log:
    aa_tls: decrypt: out_buf full (1564) -> recv_decrypted: ESP_ERR_NO_MEM
    -> tcp: client closed
    A fragmented video message (an I-frame) exceeded the fixed 96 KiB
    reassembly buffer - the same cap that was already raised from 32 KiB for
    the post-BT-handover key-frame burst. recv_decrypted now reassembles into
    per-channel buffers that grow on demand (doubling from 96 KiB, ceiling
    2 MiB) and returns the message by pointer instead of memcpy'ing it into
    plain_buf, so there is no size cap short of the ceiling and no ~100 KiB
    copy per video frame. Growth steps are logg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
    [custom.c, dev_settings.c, dev_settings.h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]
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

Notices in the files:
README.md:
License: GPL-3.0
